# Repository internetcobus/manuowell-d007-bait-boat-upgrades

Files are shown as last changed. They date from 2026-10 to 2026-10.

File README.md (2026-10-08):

# Manuowell D007 bait boat upgrades

A stock Manuowell D007 bait boat converted to a Pixhawk 2.4.8 running ArduPilot Rover, now being upgraded to brushless thrusters on 6S.

**Start with [HANDOVER.md](HANDOVER.md)**: the current state, what's next and what's still open.

## Contents

| Path | What it holds |
|---|---|
| [HANDOVER.md](HANDOVER.md) | Current state, next steps, open questions. Keep it current. |
| [docs/01-stock-vs-converted.md](docs/01-stock-vs-converted.md) | The stock boat's specs, and what the conversion changed |
| [docs/02-brushless-upgrade.md](docs/02-brushless-upgrade.md) | Thrusters, ESCs, power module, battery options and sourcing |
| [docs/03-ardupilot-setup.md](docs/03-ardupilot-setup.md) | Rover parameters for skid steering, the power module and the battery failsafe |
| [docs/04-battery-led-indicator.md](docs/04-battery-led-indicator.md) | Reusing the stock 4 LEDs as a 4S/6S battery gauge |
| [docs/sources/](docs/sources/) | Source material kept as-is, e.g. the earlier chat export |
| [designs/](designs/) | Printed parts: thruster mounts, battery lid |

## The boat in one paragraph

Used about 4 times a year to drop bait about 180 m out. The stock electronics are gone; a Pixhawk 2.4.8 with GPS runs ArduPilot Rover with twin-motor (skid) steering, controlled from a Futaba T14SG, with a 433 MHz SiK telemetry radio to a phone (QGroundControl or Mission Planner). The bait hoppers are on servos and the lights on a relay, both driven by the Pixhawk. The goal of the current upgrade is about 1 m/s loaded outbound (now about 0.7 m/s) so the fishing lines sag less.

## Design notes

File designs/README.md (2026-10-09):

# Designs

Printed parts for the upgrade, printed on the K1C (220 × 220 × 250 mm bed). Keep each part's source (OpenSCAD `.scad` or SketchUp `.skp`) and its exported STL together in a folder per part. Export STLs from SketchUp in **millimetres**: it often defaults to inches, which makes the part 25.4 times off.

Parts (the SketchUp parts are all printed and in use; **eSUN PLA+** unless noted):

- **[Thruster mounts](thruster-mount/):** **v2** designed 2026-10-09, not yet printed: a base screwed to the hull's 4 existing posts, plus a carrier that holds the thruster and slides in from the stern. (v1, the lamp-tube pylon, is shelved.)
- **[Cable holders](cable-holders/):** glued inside the hull to keep signal and power cables apart, plus the receiver antenna tube (90 degrees). SketchUp; STL only.
- **[Servo parts](servo-parts/):** hopper servo horn for the replacement metal-geared servos. SketchUp; STL only.
- **[Pixhawk bed](pixhawk-bed/):** locates the flight controller and receiver, held with a Velcro strap. SketchUp; STL only.
- **[GPS antenna spacer](gps-antenna-spacer/):** curved spacers so the GPS bracket grips the curved bow. **Solid TPU-95.** SketchUp; STL only.
- **Battery lid:** about 10 mm taller than stock, for the 6S pack's wiring. Bay is about 98 × 73 × 82 mm.
- **PM06 mount:** 35 × 35 mm board, 30.5 × 30.5 mm hole pattern.

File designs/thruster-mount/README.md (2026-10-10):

# Thruster mount

## ⭐ Version 2 (current): base + sliding carrier, on the hull's own screw posts

Designed 2026-10-09 from Cobus's measurements ([measure/](measure/)). **Not yet printed.**

| From the stern | From below |
|---|---|
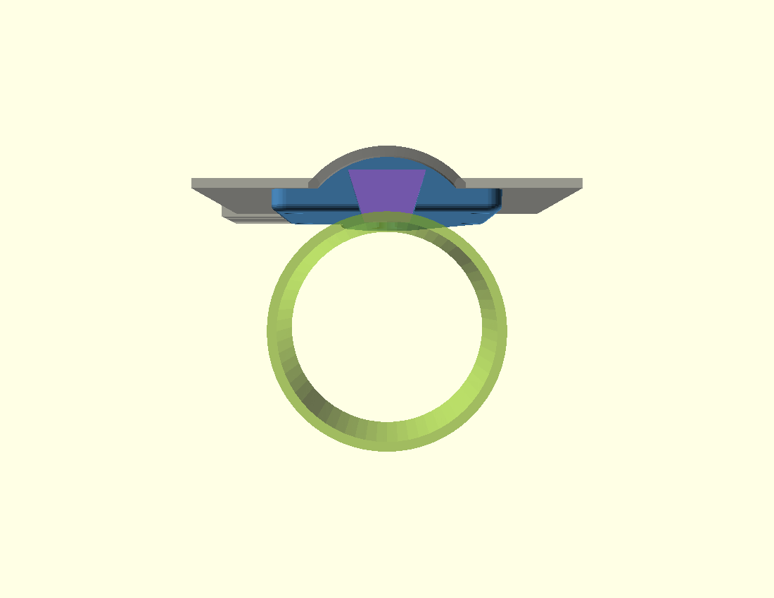
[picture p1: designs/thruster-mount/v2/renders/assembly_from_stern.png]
v2 from the stern
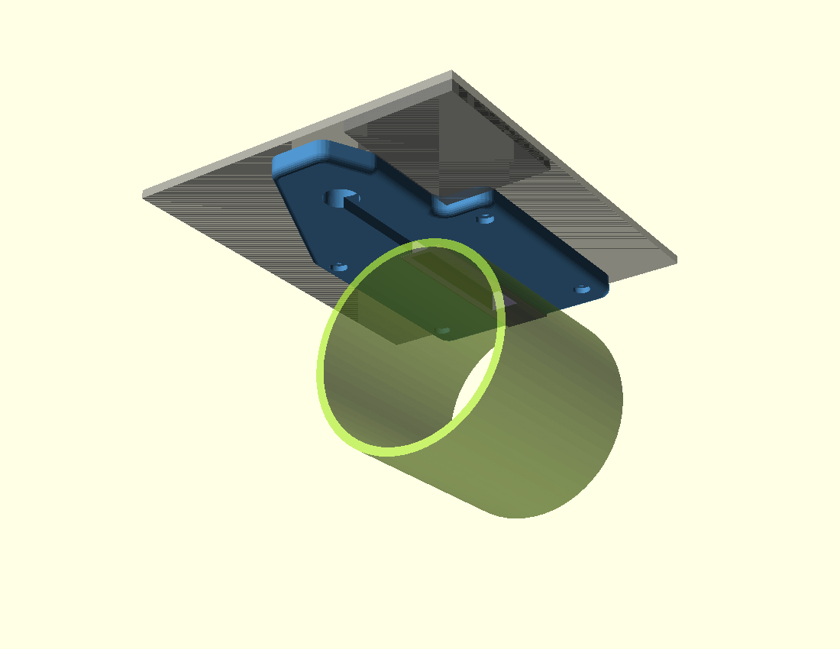
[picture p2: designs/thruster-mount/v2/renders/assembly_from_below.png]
v2 from below
|  |  |
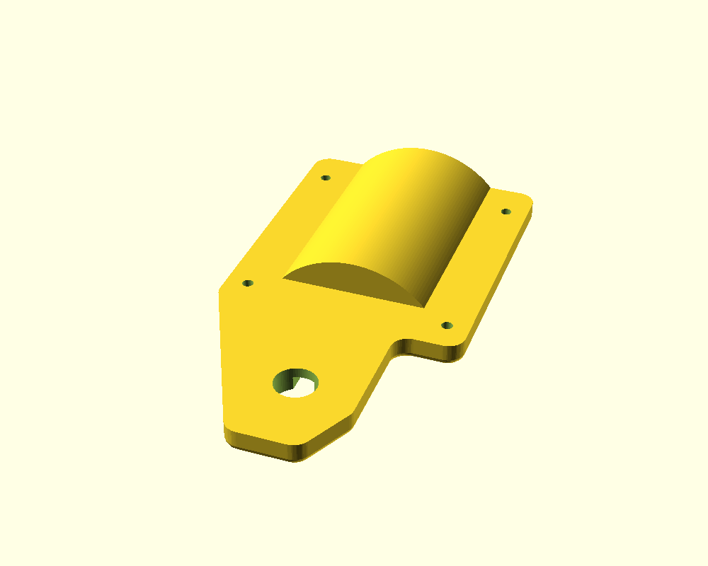
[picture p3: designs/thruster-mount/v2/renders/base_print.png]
Base, print side up
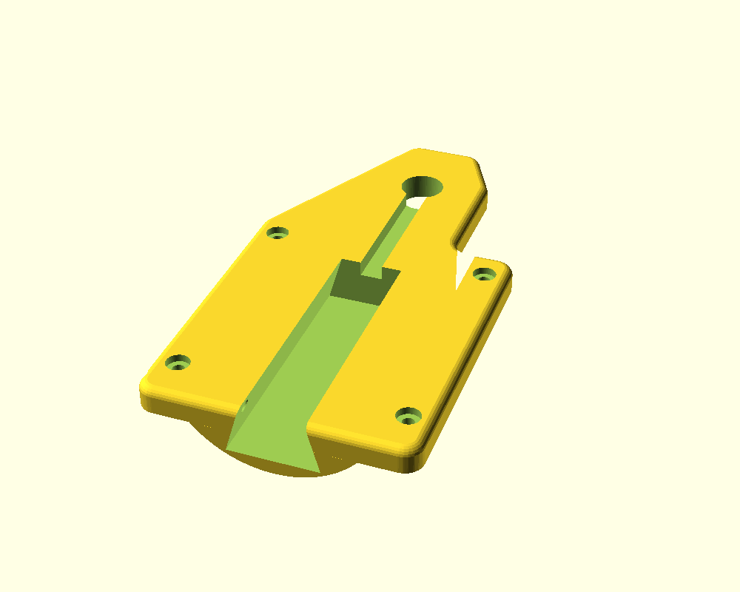
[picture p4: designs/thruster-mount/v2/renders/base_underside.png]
Base underside
|  |  |
| **Base**, as it prints: the hump fills the tunnel; corners and bottom edge rounded | **Base underside**: dovetail slot open at the stern, 4 post-screw pockets, wire channel to the wire hole |
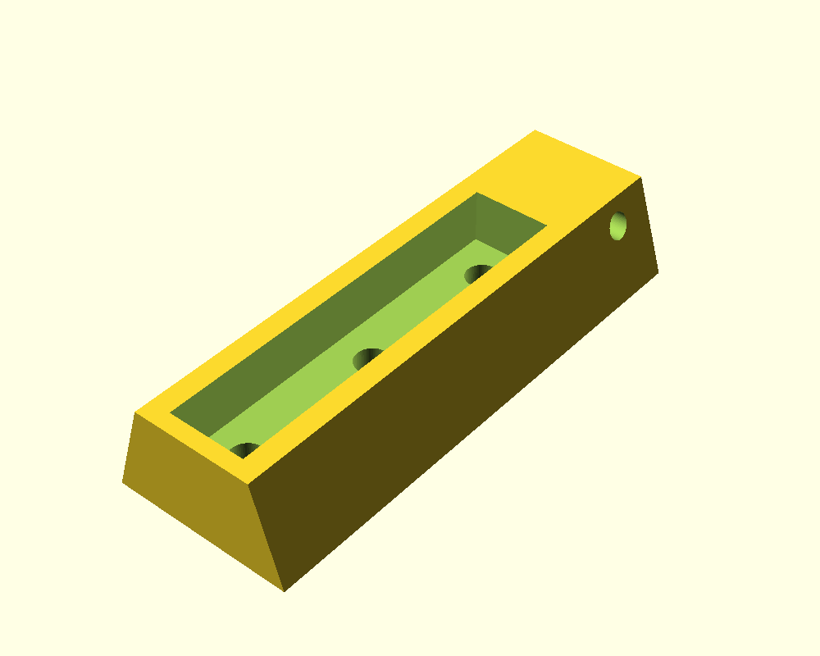
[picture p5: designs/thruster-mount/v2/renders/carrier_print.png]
Carrier
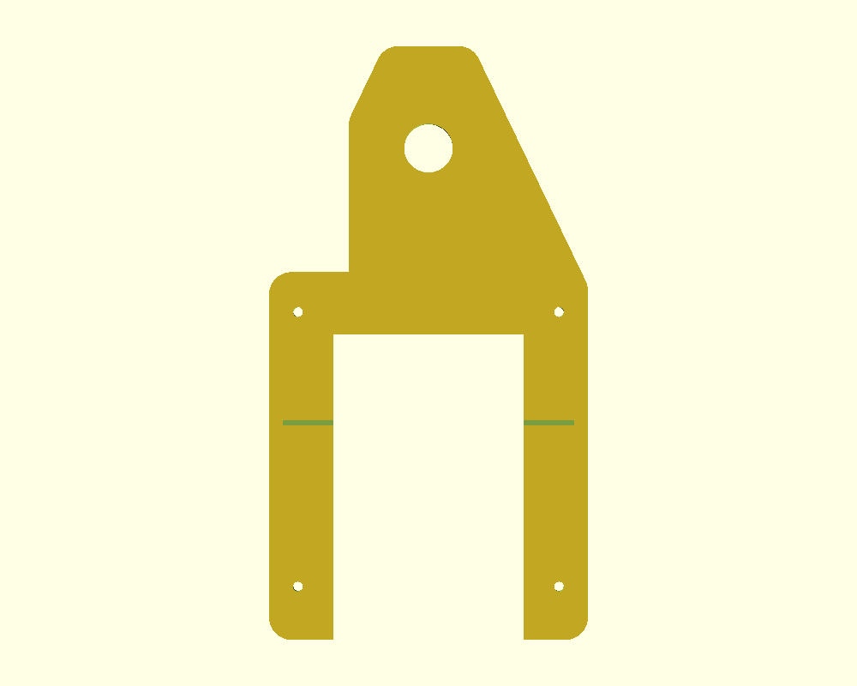
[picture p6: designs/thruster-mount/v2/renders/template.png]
Template
|  |  |
| **Carrier**, as it prints: the foot pocket, 3 M4 holes, lock-screw hole | **Template**: a 1.2 mm plate to check the 4 holes against the hull |

Each motor position has a moulded tunnel in the hull bottom (43 wide, 10 deep, 69 long) and **4 solid posts** inside that the stock motor shield screwed into from outside. The posts are closed, so the hull is already sealed there.

- **Base (blue):** fills the tunnel and screws to the 4 posts from outside, **7 mm** below the hull. Its outline corners (5 mm) and bottom edge (2.5 mm) are rounded; the top edge stays square to bed flat on the hull. The rounded stern end also gives the dovetail slot a lead-in. That gap gives water to the duct's intake. It carries on forward as a cover over the motor wires, past the wire hole to **23 mm** beyond its centre, so it also covers the hull's old mounting hole (Cobus, 2026-10-10).
- **Carrier (purple):** a dovetail bar. The thruster's foot sinks 7 mm into it and is held by 3 M4 screws from above. It slides into the base from the stern, and forward thrust pushes it against the stop at the front.
- **Lock screw:** one M3 from the **outboard** side, so reverse thrust (the boat turns by reversing one motor) can't pull the carrier out. That's why there's a left and a right version.
- **Step relief:** the strips are shallow pockets. On the **inboard** side, at 84 mm from the transom, the hull stands 4 mm proud (the template's corner caught on it, 2026-10-10). The base is **cut away** over that area (Cobus, 2026-10-10): first designed as a 4.5 mm relief, but a cover there only trapped water and added drag, and it carries no load (the nearest post screws are 10 mm aft). The cut-out's edges get the same 2.5 mm round as the rest. Where the base meets the raised area there is still a 3 mm lip, because the base's underside is 7 mm below the strip and the raised hull only 4. The outboard strip runs to the hull edge and has no step.
- **Which is which:** on each version the lock screw and the step cut-out are on opposite sides. Fit it with the **lock screw towards the hull's outer edge**; the cut-out then clears the step.

**Why two parts:** the duct's oval openings are closed, so the foot screws can only go in from above. The duct also covers the post screws. One single part could never be assembled.

**Considered and rejected, 2026-10-10: a one-piece mount.** It would be simpler to print, with no dovetail and no lock screw. But the motor would have to be bolted on first, and then the duct sits right over the 4 hull screws: the aft pair are 12 mm inside the duct's footprint, with only 15-22 mm of room below them. So they couldn't be driven from outside. It would only work with the screws driven from **inside** the hull, down through the 4 posts drilled right through. Cobus chose to keep v2: the hull stays sealed, and a motor slides out from the stern without opening the hull.

### Fitting it

0. **Remove the moulding ridge first.** A raised line about 1 mm high runs round the whole mount area: along the strips and round the wire-hole recess ([Cobus's blue line](photos/20261010_ridge_marked_cobus.jpg), 2026-10-10). The base sits on it, which is what lifted the dovetail test piece. Shave it flush with a chisel held bevel-up and flat, or a scraper, then a sanding block (~240). Never go below the surface; the hull is about 3 mm. Check with a straight edge. The sanding also gives the epoxy a key.
1. **Pilot holes:** open the hull's 2 mm holes to **2.4 mm**, about **12 mm deep** from outside. Tape round the drill bit marks the depth. Hull and post together are 17.5 mm, so this leaves the post's closed top intact. Do one post first and check it doesn't crack.
2. **Base:** screw it to the 4 posts with **ST2.9 × 13**, with the thruster off. A dab of marine sealant on each screw stops water wicking into the posts. Epoxy bedding is **optional** (decided 2026-10-10): at about 6 N per screw at full thrust, the screws carry the load. Bedding would only help spread knocks.
3. **Foot holes:** drill the thruster foot's 3 mm holes out to **3.3 mm** and tap them **M4**, to their existing depth only. **Never drill through.** The foot sits on the duct, and a bolt end would hit the propeller.
4. **Carrier:** bolt the foot into it on the bench, with 3 × **M4 countersunk**. Drop the M3 nut into its slot in the carrier's top.
5. **Assemble:** slide the carrier in from the stern until it stops, then fit the **M3 × 40** lock screw from the outboard side.
6. **Wires:** run them along the channel and up through the wire hole. Seal the hole with a cable gland or potting.

### Parts for both sides

| Qty | Part | For |
|---|---|---|
| 8 (+ spares) | **ST2.9 × 13** stainless pan-head self-tapper | Base to the 4 posts, each side |
| 6 | **M4 countersunk** stainless, about **× 12**. Length to check: 6.1 mm goes through the carrier, the rest into the foot | Foot to carrier |
| 2 | **M3 × 40** stainless machine screw + **2 M3 nuts** | Lock screws |
| 1 each | 2.4 mm and 3.3 mm drill, **M4 tap** | Pilot holes and foot holes |
| 1 | Marine sealant (e.g. Sikaflex); thickened epoxy only if you choose to bed the bases | Screws, and optional bedding |
| 2 | Cable gland, or sealant to pot the wire holes | Wire holes |
| — | ABS (or ASA) filament | Bases and carriers |

The v1 shopping list (lamp tube, nuts, rubber washers) is no longer needed.

### Print and check first

| File | Check |
|---|---|
| `v2/v2_template_right.stl`, `v2/v2_template_left.stl` | Lay it on the hull. Do the 4 holes land on the 2 mm pilot holes, does the window match the tunnel, and does it now sit flat past the step? ✅ 2026-10-10: the first template (no notch) matched all 4 holes; only the corner on the step lifted it. It's a flat plate, so one turned over is the other. |
| `v2/v2_fit_dovetail_ladder_right.stl` | **Clearance ladder, print in ABS.** Three 14 mm base slices, marked with 1 / 2 / 3 notches = **0.10 / 0.15 / 0.20 mm** a side, plus a 14 mm carrier. Pick the slice the carrier slides into with a light push and no wobble; I then set `dv_clear` to it. **Result (2026-10-10, ABS): 0.10 fits best, no wobble; `dv_clear` is now 0.10 and the base and carrier STLs are re-exported.** |

**First dovetail test (2026-10-10, PLA):** the M3 nut dropped in perfectly, but the carrier had play all round. The cause was the design, not the PLA. The walls were only about 9° off vertical (18 / 22 mm), so 0.3 mm of side gap let the carrier sink about **2 mm**: drop = gap ÷ wall slope. Now 16 / 24 mm (twice the slope) at 0.15 mm a side: the carrier sinks about 0.5 mm. ABS wouldn't have fixed it, because both parts shrink alike.
| `v2/v2_base_right.stl`, `v2/v2_carrier_right.stl` | Right-hand thruster: lock screw from the right (outboard) side |
| `v2/v2_base_left.stl`, `v2/v2_carrier_left.stl` | Left-hand thruster |

Print in ABS or ASA (not PLA: sun and water), 4+ walls, 40 %+ infill. Both parts are already laid flat for printing: the base on its underside, the carrier on its top.

### Not yet measured (marked `VERIFY` in the .scad)

- **The rail across the tunnel:** no groove for it (Cobus, 2026-10-09). It's only 0.5 mm high, and the base sits 0.3 mm off the tunnel roof for the epoxy, so the bedding takes it up. If the base rocks on a dry fit, sand the rail down. The groove can be switched back on with `rail_groove = true`; its position (49 mm from the transom) was read off photo 1 by scale, and the template's scribed line checks it.
- **The wire hole:** about 11 mm across.
- **How deep the foot's 3 holes go.** That decides the M4 screw length.
- **Where the raised area starts across:** taken from 18 mm off the centreline (`step_x0`; the tunnel's frame line is at 21.5). **Also check the other tunnel** has the same step on its inboard side; the model assumes the hull is mirror-symmetric.

### Files

`thruster_mount_v2.scad` is the source. Set `part` to `base`, `carrier`, `template`, `fit_dovetail` or `all`, and `side` to `right` or `left`. Its `assert`s stop a change that would make the carrier hit the hull or leave too little plastic. For both sides, OpenSCAD intersections show the base, carrier, hull (including the step) and thruster don't overlap; the only contact is the wings on the hull, the bedding face. Negative tests prove the checks work: with the step cut-out moved away, the base and hull overlapped by 441 mm³; with the slot too tight, base and carrier overlap by 408 mm³. Both base STLs are one closed solid. `part = "none"` draws nothing, for check scripts that `include` the file. Re-export after any change, e.g.
`openscad -D 'part="base"' -D 'side="left"' -o v2/v2_base_left.stl thruster_mount_v2.scad`

---

## Version 1 (shelved 2026-10-09)

Shelved because the hull turned out to have its own tunnel and screw posts, and the lamp tube only came in 15 mm locally. Kept for the record.

A printed pylon that hangs each 62 mm brushless thruster from the **stock motor-post hole**, on a **steel hollow M10 × 1 lamp tube** that also carries the wires. The hull gets no new holes. The part is symmetric, so print two.

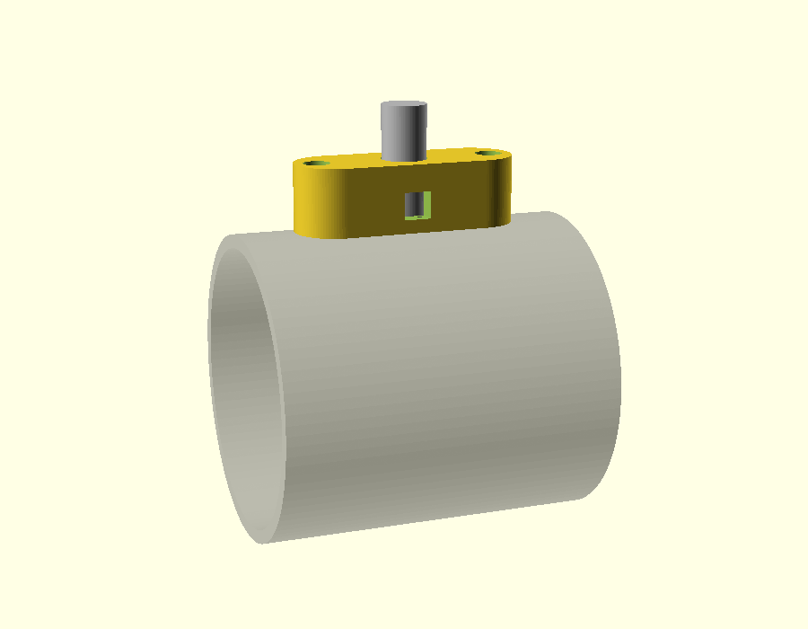
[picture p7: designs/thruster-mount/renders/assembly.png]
Pylon on a dummy thruster


| Render | |
|---|---|
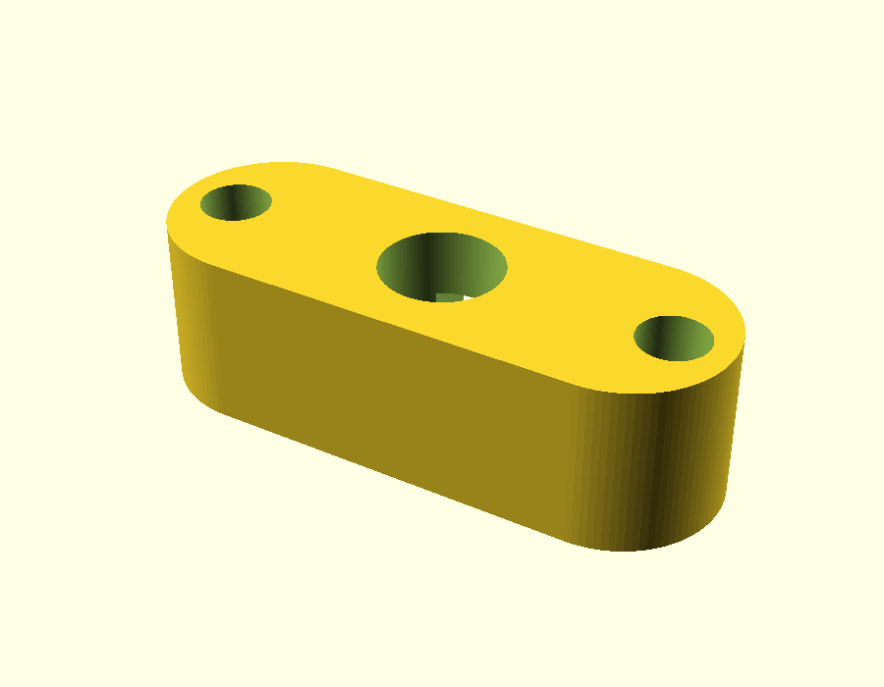
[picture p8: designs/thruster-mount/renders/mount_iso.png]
Hull face
|  | Hull face: tube bore in the middle, screw-head pockets at each end |
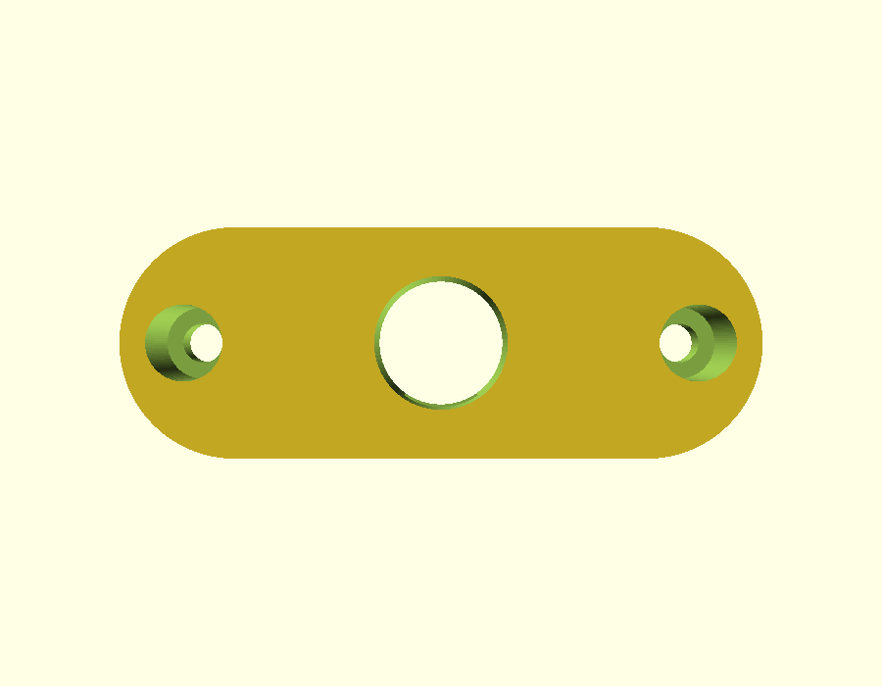
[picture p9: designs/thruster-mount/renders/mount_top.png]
Underside
|  | Looking down through it: the screw clearance holes under the head pockets |

## Status (2026-10-08)

**Version 1, not yet printed.** It is designed from the stock pod's dimensions and the thruster specs; nothing has been measured on the boat yet. Print the two fit tests first.

## How it goes together

```
 inside hull     inner nut + steel washer + rubber washer
 ════════════════╪═══════════════  hull, existing 11 mm hole
                 │  ring of marine sealant on the pylon's top face
             ┌───┴───┐
             │ pylon │  the tube threads into a nut captured in the pylon's base
             └─┬───┬─┘  the wires leave through the side slot
          ╭────┴───┴────╮
          │  thruster   │  2 screws, 40 mm apart, heads inside the pylon
          ╰─────────────╯
```

1. Press an M10 × 1 lamp nut into the hex pocket in the pylon's base.
2. Bolt the pylon to the thruster: two screws down through the head pockets into the thruster's **outer** two holes. The middle hole sits under the tube and stays empty.
3. Thread the tube into the captured nut, flush with the nut's underside. Feed the thruster's three wires in through the side slot and up the tube.
4. Run a ring of marine sealant (e.g. Sikaflex) round the tube on the pylon's top face. Keep it **inside** the head pockets: less than 7 mm from the tube's centre.
5. Push the tube up through the stock hole. Inside the hull, fit a rubber washer, a steel washer and the inner nut, then tighten it so the pylon clamps the hull. **Line the thruster up with the boat's centreline before the sealant sets.** The sealant is also what stops the pylon twisting.
6. Seal the wires where they leave the top of the tube, e.g. with silicone or adhesive-lined heat-shrink.

## Parts per side

| Part | Note |
|---|---|
| Printed pylon | ASA, 4+ walls, 40 %+ infill, thruster face down on the bed (as modelled) |
| M10 × 1 hollow steel lamp tube | Cut to **27 mm** (the `.scad` prints the length for the current settings) |
| 2× M10 × 1 lamp nuts | One captured in the pylon, one inside the hull |
| M10 steel washer + rubber washer | Inside the hull |
| 2× M3 socket-head screws, stainless | **Length to be decided** once the thruster's holes are checked. The pylon gives 4 mm of grip. |
| Marine sealant | Sikaflex or similar |

## Check these before printing the full pylon

Every value marked `VERIFY` in `thruster_mount.scad` is an assumption:

- **The thruster's holes:** three 3 mm holes in a line along the top, 20 mm apart (Cobus, 2026-10-08). The pylon uses the outer pair, 40 mm apart. Still to check: are they threaded? A tapped M3 hole measures about 2.5 mm, so 3 mm may mean plain holes for self-tappers.
- **50 mm of flat hull at each post hole.** The pylon is 50 mm long to reach the outer holes; the stock pod's saddle was only 35 mm.
- **The lamp nut:** 13 mm across the flats and 3 mm thick is assumed. Measure the ones you buy and set `nut_af` and `nut_h`.
- **The hull wall at the post hole:** 3 mm assumed. It only changes the tube length.
- **The duct's outside diameter:** 68 mm assumed (62 mm opening plus about 3 mm walls). With the 15 mm `drop`, the thruster's axis sits about 49 mm below the hull. Check that against how shallow the water is where you launch.
- **Is the hull flat where the pylon sits?** If not, the top face needs to follow the curve.

## Fit tests (a few grams each)

| File | What to check |
|---|---|
| `thruster_mount_fit_bottom.stl` | The two screw holes line up with the thruster's outer holes; the lamp nut presses in and doesn't spin; the tube threads in |
| `thruster_mount_fit_top.stl` | The hull face sits flat against the hull at the post hole |

## Files

- `thruster_mount.scad`: the source. Set `part` to `mount`, `fit_bottom`, `fit_top`, or `all` (an assembly preview, not for printing). Its `assert`s stop a parameter change that would break a wall.
- `thruster_mount_*.stl`: exported from the current settings. Re-export after any change:
  `openscad -D 'part="mount"' -o thruster_mount_mount.stl thruster_mount.scad`
- `renders/`: preview images. OpenSCAD is a snap here and can't write to `/tmp`, so render into the repo.

## Design notes

- **Why a steel tube:** about 1.7 kg of thrust per side bends the post where it meets the hull. A printed 11 mm post would see roughly 7 MPa there, close to where printed layers separate, and the load repeats on every run.
- **Why the outer pair of holes:** the thruster's middle hole is directly under the tube. Using the outer two, 40 mm apart, keeps the tube centred and resists the thrust better than a 20 mm pair.
- **Why sealant, not an O-ring:** the sealant also stops the pylon twisting, and it copes with a hull that isn't perfectly flat. Sealant on the face plus the rubber washer inside the hull do the sealing.
- **Footprint:** 50 × 18 mm, long enough for the outer screw pair, with rounded ends to keep it streamlined.
- **If a pylon still twists:** set `pin_d` (e.g. 3.2) to add a locating pin. That needs one small new hole in the hull.

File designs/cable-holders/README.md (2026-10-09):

# Cable holders

Drawn by Cobus in SketchUp during the upgrade. Added 2026-10-08 from `Cable holders.stl`.

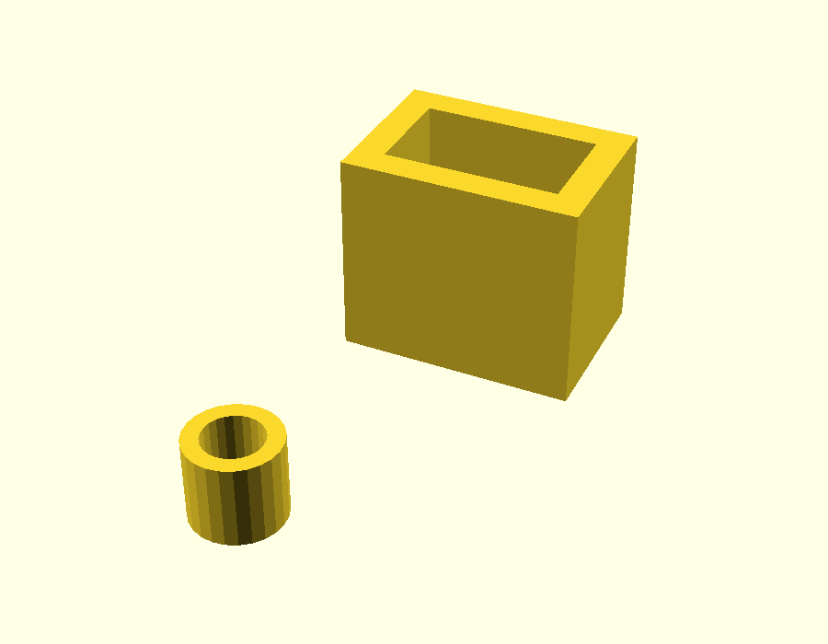
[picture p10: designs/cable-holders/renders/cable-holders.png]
Cable holders
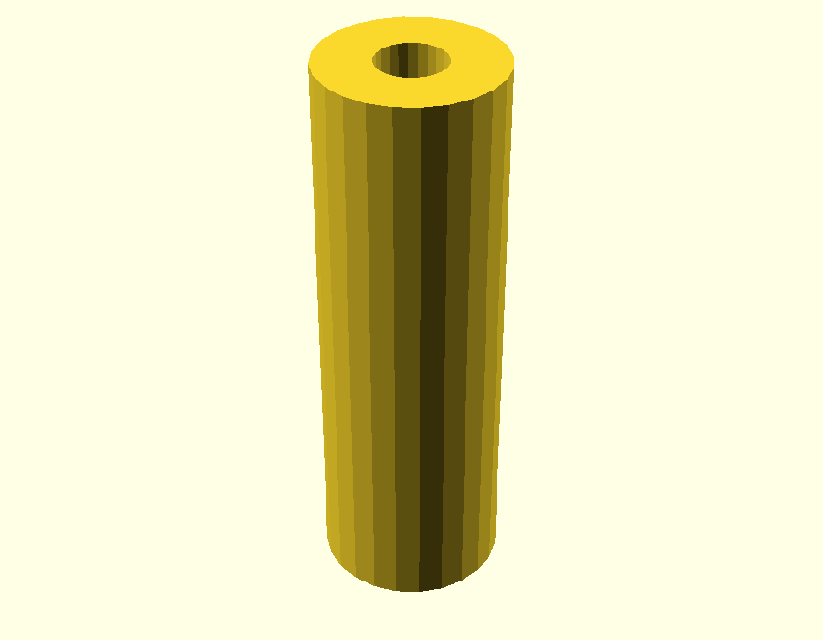
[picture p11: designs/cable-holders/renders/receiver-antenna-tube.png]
Receiver antenna tube
|  |  |
|---|---|
| `cable-holders.stl` | `receiver-antenna-tube.stl` |

## What it's for

Glued to the inside of the hull to keep the **signal cables and the power cables apart**. The cables run through the inside of these parts.

The **receiver antenna tube** holds the receiver's antenna wire at **90 degrees** for the best signal. It was drawn on the [GPS antenna spacer](../gps-antenna-spacer/) plate and moved here on 2026-10-09 as its own file.

Described by Cobus, 2026-10-09. **Printed in eSUN PLA+ and in use.**

## What's in the file

In millimetres:

| File | Part | Size (mm) |
|---|---|---|
| `cable-holders.stl` | Round spacer, with a hole through it | 8.9 × 8.9 × 8.0 |
| `cable-holders.stl` | Open-topped rectangular box | 23.0 × 16.0 × 20.0 |
| `receiver-antenna-tube.stl` | Tube, 2.5 mm bore (measured from the mesh) | 6.5 × 6.5 × 20.0 |

Both meshes are watertight (no open edges). The tube's triangles were copied unchanged from the GPS spacer plate.

## Source

The SketchUp `.skp` file isn't in the repo yet. Add it here as `cable-holders.skp` so the original can be reopened and changed.

## Changing it

Without the `.skp`, changes are made on this STL in OpenSCAD: adding or cutting features, or scaling. Redrawing it as a parametric `.scad` is the better route if it will keep changing.

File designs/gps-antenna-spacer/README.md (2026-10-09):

# GPS antenna spacer

Drawn by Cobus in SketchUp during the upgrade. Added 2026-10-08 from `GPS antenna spacer.stl`.

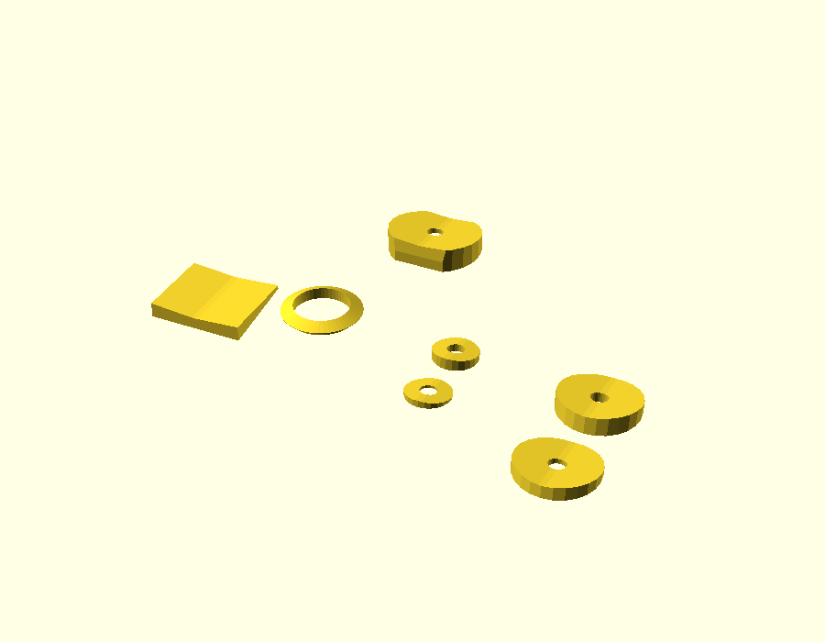
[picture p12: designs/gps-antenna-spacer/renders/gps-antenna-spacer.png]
GPS antenna spacer


## What it's for

The GPS antenna is mounted on the **front of the hull, on the centreline**. The hull isn't flat there, so these curved spacers sit between the antenna bracket and the hull: the bracket can be tightened firmly and still grip the curve.

Described by Cobus, 2026-10-09. **Printed in solid TPU-95** (100 % infill), so the spacers flex to follow the hull's curve exactly. **In use.**

The original plate also held the receiver antenna tube. That isn't a GPS part, so on 2026-10-09 it moved to the [cable holders](../cable-holders/) as `receiver-antenna-tube.stl`.

## What's in the file

`gps-antenna-spacer.stl` is a print plate with 7 parts, in millimetres:

| Part | Size (mm) |
|---|---|
| Curved square pad | 17.0 × 14.0 × 2.7 |
| Ring | 14.4 × 14.4 × 2.1 |
| Shaped washers with a hole (4) | about 14-17 × 14 × 2.2-4.4 |
| Small washers (2) | 8.0 × 8.0 × 1.2 and 2.2 |

Watertight mesh (no open edges). The plate is now 7.3 mm tall (it was 22 mm with the tube).

**Print in TPU-95, solid.** In PLA+ these spacers wouldn't follow the curve, and the bracket would rock.

## Source

The SketchUp `.skp` file isn't in the repo yet. Add it here as `gps-antenna-spacer.skp` so the original can be reopened and changed.

## Changing it

Without the `.skp`, changes are made on this STL in OpenSCAD: adding or cutting features, or scaling. Redrawing it as a parametric `.scad` is the better route if it will keep changing.

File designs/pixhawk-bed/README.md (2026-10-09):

# Pixhawk bed

Drawn by Cobus in SketchUp during the upgrade. Added 2026-10-08 from `Pixhawk 4 bed.stl`.

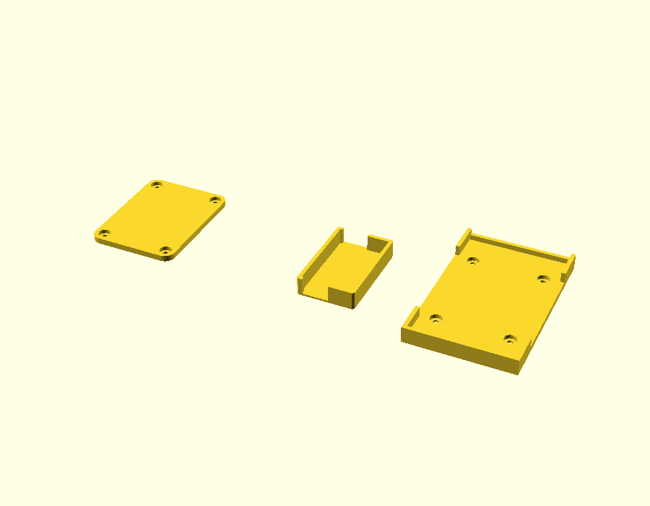
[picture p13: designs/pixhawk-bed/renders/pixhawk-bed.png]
Pixhawk bed


## What it's for

Holds the **flight controller and the RC receiver** in the right position, secured with a **Velcro strap**.

Described by Cobus, 2026-10-09. **Printed in eSUN PLA+ and in use.**

## What's in the file

`pixhawk-bed.stl` is a print plate with 3 parts, in millimetres:

| Part | Size (mm) |
|---|---|
| Flat plate, 4 corner holes | 44.5 × 59.0 × 3.0 |
| Small open tray | 29.0 × 46.8 × 9.0 |
| Large tray with side rails and 4 holes | 53.6 × 85.5 × 8.0 |

🚨 The mesh has **12 open or doubled edges**; most slicers repair this on import.

🚨 As laid out, the plate is **220.05 mm** wide, just over the K1C's 220 mm bed. Move the parts closer together in the slicer.

The file is called "Pixhawk 4 bed" but the boat runs a Pixhawk 2.4.8. The large tray (53.6 × 85.5 mm) would fit a 2.4.8, which is about 50 × 81.5 mm.

## Source

The SketchUp `.skp` file isn't in the repo yet. Add it here as `pixhawk-bed.skp` so the original can be reopened and changed.

## Changing it

Without the `.skp`, changes are made on this STL in OpenSCAD: adding or cutting features, or scaling. Redrawing it as a parametric `.scad` is the better route if it will keep changing.

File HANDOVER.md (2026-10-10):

# Handover: current state

_Last updated: 2026-10-10_

## Where things stand

- **Running today (working well):** Pixhawk 2.4.8 + GPS on ArduPilot Rover, stock 390 brushed thrusters on two CL9030 brushed ESCs, stock 7.4 V 10 Ah Li-ion pack. The Pixhawk is powered from an ESC's 5 V output, so it cannot read the battery yet.
- **Brushless upgrade:** 480 Kv ducted thrusters (CW/CCW pair) and two BLHeli 40 A bidirectional ESCs ordered. Duct opening measured at 62 mm, which confirms the thrusters match the specs in [the chat export](docs/sources/2026-10-08-earlier-chat-export.md), not the 1000 KV listing.
- **Decided:** go **6S**. Cap `MOT_THR_MAX` at about 90%, because a full 6S pack (25.2 V) is slightly over the 24 V rating.
- **Power module:** Holybro **PM06** on hand, **not fitted yet**.

## Next steps

1. Wait for the thrusters; bench test them with the props in water.
2. Decide the pack: 2× Auline 21700 S70 6S 4500 mAh in parallel (AliExpress), or a no-BMS Molicel P42A 6S2P (Akita or DIY). See [docs/02](docs/02-brushless-upgrade.md).
3. Weigh the stock battery; do the bath/ballast hull test.
4. **Thruster mounts: v2** ([designs/thruster-mount](designs/thruster-mount/)). A base screwed to the hull's 4 existing posts (ST2.9 × 13) and a dovetail carrier that holds the thruster (3 × M4 into the tapped foot), slides in from the stern and is locked by one M3 × 40 from the outboard side. Left and right versions.
   - **Tested 2026-10-10:** the template's 4 holes line up. The base is now cut away over a 4 mm step on the inboard side (84 mm from the transom). A ~1 mm gap on the curve came from a moulding ridge round the mount area, which Cobus shaved flush. The first dovetail (PLA) was loose because its walls were too steep; it's now 16/24 mm, and the ABS clearance ladder picked **0.10 mm** (no wobble). The wire cover now runs 23 mm past the wire hole to cover the old mounting hole.
   - **Decided:** stay with two parts (one-piece rejected, see the mount README); epoxy bedding optional.
   - **Confirmed 2026-10-10:** ridge shaved and the base now sits well; the reprinted template (with the 23 mm tip) fits; the other tunnel has the same inboard step, so the left part's mirrored cut-out is right.
   - **Next:** a PLA+ mock-up of the right base and carrier with the thruster fitted, to check the whole assembly. Then measure the foot holes' depth (M4 length) and the wire hole, buy the screws, print the real parts.
   - Still to design: the taller battery lid.
5. **SketchUp parts added 2026-10-08** (STL only): [cable holders](designs/cable-holders/), [servo parts](designs/servo-parts/), [Pixhawk bed](designs/pixhawk-bed/), [GPS antenna spacer](designs/gps-antenna-spacer/). All printed and in use: eSUN PLA+, except the GPS spacers in solid TPU-95. Purposes recorded 2026-10-09; the receiver antenna tube moved to `cable-holders/`. Still to do: add the `.skp` files beside the STLs.
6. Fit the PM06; configure the Rover parameters and battery failsafe ([docs/03](docs/03-ardupilot-setup.md)); build the LED indicator ([docs/04](docs/04-battery-led-indicator.md)).

## Open questions

- **PM06 connector:** the PM06 ends in a 6-pin JST-GH plug; the Pixhawk 2.4.8 power port is a 6-pin DF13. An adapter cable is needed. Check which PM06 version it is (V1 is 2S-6S, V2 is 2S-14S); either covers 6S.
- **5 V supply:** with the PM06 powering the Pixhawk, decide what each ESC's 5 V / 3 A BEC feeds (servos? LED MCU?). Never connect two BECs to the same rail.
- Which Pixhawk outputs drive the relay and the hopper servos (motors: `SERVO1` / `SERVO3`).
- Which RC receiver is paired with the T14SG, and how it connects (SBUS?).
- Which failsafes are configured today.
- Rover is set up as a Rover with twin motors, not the Boat frame (`FRAME_CLASS = 2`). It may be worth trying Boat.

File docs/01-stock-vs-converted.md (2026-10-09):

# Stock vs converted

Conversion done before 2026-10-08: the stock electronics were removed and replaced with a Pixhawk.

| Item | Stock D007 | Converted |
|---|---|---|
| Control electronics | Stock board | Removed; **Pixhawk 2.4.8** and the RC receiver on a printed [bed](../designs/pixhawk-bed/) with a Velcro strap |
| Firmware | Stock | **ArduPilot Rover**, twin drive motors (skid steering) |
| Navigation | Built-in GPS + compass, limited: 3 stored fishing spots, auto-pilot to a spot, auto-return | **GPS** on the Pixhawk; full missions and waypoints. Antenna on the bow, on the centreline, on printed [curved spacers](../designs/gps-antenna-spacer/) |
| Failsafes | Low-power alarm, low-power auto-return, lost-signal auto-return | Rover failsafes (what is configured is not yet recorded) |
| RC | Stock remote, about 500 m range; the shop page also lists "4G mobile" | **Futaba T14SG** |
| Telemetry | None | **SiK 433 MHz** on **TELEM1**, to a phone (QGroundControl or Mission Planner) |
| Motor drive | Stock board | Two **CL9030** brushed ESCs, one per motor |
| Motors | Two 390 brushed thrusters (see below) | Unchanged |
| Lights | Two LEDs, front and rear | Switched by a **relay** from the Pixhawk |
| Battery | 7.4 V 10 Ah Li-ion | Unchanged |
| Battery indicator | 4 LEDs (3 blue + 1 red), 2S only | Planned rebuild, see [04](04-battery-led-indicator.md) |
| Pixhawk power | n/a | From an ESC's 5 V output; no battery reading |
| Wiring | Stock | Signal and power cables kept apart by printed [cable holders](../designs/cable-holders/); the receiver antenna held at 90 degrees |
| Bait hoppers | Two side-release hoppers, 2 kg total, on **continuous-rotation** servos | **Normal (positional) metal-geared servos** on Pixhawk outputs, with a printed horn ([servo parts](../designs/servo-parts/)) |
| Fish finder | Not supported | — |

## Stock specs

Source: [Carpe Diem Online, D007 Classic Series](https://carpediemonline.co.za/online-store/d007-classic-series/). The page's heading reads **D008**, although the URL says D007, so a figure may belong to the D008.

- **Hull:** 53 × 33 × 22 cm overall, hull 50 × 30 × 18 cm, virgin ABS, carbon-fibre finish, 3 kg, stainless steel folding handle.
- **Battery:** D008/V017 pack, 7.4 V, 10 Ah, Li-ion, 10 × 5 × 4 cm, listed at 0.5 kg (the export estimates about 400 g; to be weighed). R1,127 as a spare from [Carpe Diem Online](https://carpediemonline.co.za/online-store/d008-v017-battery-10ah/).
- **Battery bay:** about 98 × 73 × 82 mm. A taller lid can be printed.
- **Motors:** a pair of SkyArea 390-size brushed underwater thrusters ([AliExpress](https://www.aliexpress.com/item/1005006050172879.html), R340 a pair): 30 W, rated 5-12 V, about 10,000 rpm, 26 mm 3-blade prop, ABS shell, silicone seal. About 130 mm long overall (87 mm body), mounted on an 11 mm threaded post (37 mm tall, 28 mm threaded). No current rating listed; about 4 A each running, by estimate from 30 W at 7.4 V.
- **Performance today:** about 0.7 m/s loaded.

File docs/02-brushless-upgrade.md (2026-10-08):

# Brushless upgrade

## Goal

About **1 m/s loaded outbound** (now about 0.7 m/s) so the fishing lines sag less, which is a thrust problem. About 2 m/s empty on the return is a bonus. Loaded speed is capped by hull speed, about 0.9-1 m/s for a hull this size, so the extra thrust shows more on the return.

## Thrusters (ordered, AliExpress)

Brushless, ducted, 4-blade, CW/CCW pair:

- **480 Kv**, 12-24 V, 13 A, 30-200 W, about **2 kg thrust each at 24 V**
- 162 g each, 75 mm long, **62 mm diameter** (duct opening measured 2026-10-08), 250 mm leads
- Mounting: **three 3 mm holes in a straight line along the top, 20 mm apart** (Cobus, 2026-10-08). Threaded or plain not yet checked. The [thruster mount](../designs/thruster-mount/) uses the outer pair.

A different listing, [KINGMODEL 4000074645091](https://www.aliexpress.com/item/4000074645091.html), was looked at on 2026-10-08. It describes 1000 KV / 20 A / 74 mm thrusters with a PLA shell and a semi-submersible prop. The 62 mm measurement shows these are not those thrusters, so ignore that listing's figures.

## ESCs (ordered)

Two BLHeli ESCs: **40 A (50 A burst), 2S-6S, 5 V / 3 A BEC, bidirectional**, programmable. They replace the CL9030s, which are brushed only.

## Power module

Holybro **PM06**, on hand, not fitted yet. Per [Holybro's PM06 V2 specs](https://www.getfpv.com/electronics/autopilot-systems/pm06-14s-power-module.html): 2S-14S, 60 A rated (120 A for under 60 s), 5.1-5.3 V / 3 A output to the Pixhawk, XT60 on 12 AWG (rated 30 A continuous, 60 A for under a minute), 35 × 35 mm, 24 g. The original PM06 (V1) is 2S-6S. Either version covers 6S.

- **Connector:** the PM06 has a 6-pin **JST-GH** cable; the Pixhawk 2.4.8 power port is a 6-pin **DF13**. An adapter cable is needed.
- The XT60 lead is rated 30 A continuous. Full throttle on 6S is about 26 A in total, so that's within its rating but close.

## Why 6S

The rated thrust is at 24 V. 4S gives only about 0.75-1 kg per thruster; 6S about 1.7 kg. A full 6S pack is 25.2 V, slightly over the 24 V rating, so cap `MOT_THR_MAX` at about 90%.

## Battery options

Energy: about 14 Wh per drop at cruise, about 33 Wh per drop at full throttle on 6S. Plan on 80% of the pack being usable.

| Pack | Weight | Top speed loaded / empty | Drops cruise / full |
|---|---|---|---|
| 4S 5500 LiPo | ~550 g | 0.9-1.1 / 1.5-1.8 m/s | ~4-5 / same |
| 6S 5000 LiPo | ~750 g | 1.2-1.4 / 2+ m/s | ~6 / ~2-3 |
| 6S1P 21700 P42A | ~420 g | 1.15-1.3 / ~2 m/s | ~5 / ~2 |
| 6S2P 21700 P42A (8,400 mAh, ~181 Wh) | ~880 g | 1.2-1.4 / 2+ m/s | ~10 / ~4 |

- Both LiPos (5000+ mAh) are probably too long for the 98 mm bay. Measure first.
- A 6S2P P42A pack is about 450-500 g heavier than the stock pack; the whole upgrade is about 750-800 g over stock.
- **6S2P fit:** a 4 × 3 upright brick is about 88-92 × 66-70 × 74-78 mm and fits the bay. Glue the cells, no printed holders; a lid about 10 mm taller for the wiring.

## Sourcing (South Africa)

- **Molicel P42A** (21700, 4200 mAh, 45 A): DIYElectronics (~R209), The Vapery, Vaporworx (~R230), Vanilla Vape.
- **Akita Custom Batteries** (Randburg, 011 704 2429, info@akita.co.za) quoted a 6S2P Samsung 30P (6,000 mAh) with a 12 A BMS for R2,662 incl. VAT.
  - The 12 A BMS is too small: full throttle is about 26 A. They have no 30 A BMS.
  - Their concern about the P42A was mistaken; it is rated 45 A per cell.
  - Fix: ask for **no BMS** (XT60 plus a 7-pin JST-XH balance lead) or a charge-only BMS.
- **AliExpress best fit:** 2× **Auline 21700 S70 6S 4500 mAh** (75 × 64 × 42 mm, 70 A each) in parallel, about 9,000 mAh, standing side by side in the bay.
  - Buy a matched pair, parallel them only at equal voltage, with an XT60 Y-harness.
  - Check whether lithium ships to South Africa.

## Hull

Probably fine for now. Risks: pod mounting strength under thrust, stern freeboard, ESC heat.

- **Bath test:** about 1 kg of ballast plus a full bait load. 3 cm or more of freeboard is OK; about 2 cm is marginal.
- **Fallback:** print a hull on the K1C (220 × 220 × 250 mm bed) in sections, in ASA, with an epoxy or fibreglass skin.

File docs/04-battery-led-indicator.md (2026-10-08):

# Battery LED indicator

The stock boat has a 4-LED battery gauge (3 blue + 1 red) that only understands 2S. The plan (options 1 + 3 from the [chat export](sources/2026-10-08-earlier-chat-export.md)): reuse those LEDs, driven by a small microcontroller, with the Pixhawk battery failsafe as the real safety net.

## Hardware

- MCU: ATtiny85, Nano or ESP32.
- Battery voltage through a divider, e.g. 100k / 10k.
- Powered from an ESC's 5 V BEC.
- Bypass the stock board: cut its battery feed, isolate the LEDs from its chip, and drive them through resistors: 150-330 Ω for blue, 220-470 Ω for red, at 5 V.

## Logic

Auto-detect 4S or 6S at power-up, then show the per-cell voltage:

| Per cell | LEDs |
|---|---|
| 3.95 V or more | 3 blue |
| 3.80 V or more | 2 blue |
| 3.65 V or more | 1 blue |
| below 3.65 V | red |
| below 3.5 V | red, flashing |

These thresholds suit LiPo. Lower them for Li-ion.

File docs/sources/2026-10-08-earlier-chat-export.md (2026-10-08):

# Manuowell D007 Bait Boat — Motor & Battery Upgrade (Session Export)
Exported: 8 Oct 2026

## Boat & current setup
- Manuowell D007 bait boat, used ~4×/year, drops ~180 m out
- Pixhawk 2.4.8 + GPS on ArduPilot Rover (working well); telemetry via SiK radio to phone
- Stock thrusters: 390 brushed, 7.4V/2S, ~10,000 RPM, 26 mm 3-blade prop, inline pods
- Stock battery: 7.4V 2S Li-ion, ~10 Ah (~400 g est. — weigh to confirm)
- Battery bay: ~98 × 73 × 82 mm (can print a taller lid)
- Stock 4-LED voltage indicator (3 blue + 1 red), 2S only

## Goal
- ~1 m/s loaded outbound so fishing lines sag less (thrust problem); ~2 m/s empty return is a bonus
- Current loaded speed: ~0.7 m/s

## Thrusters & ESCs (ordered, AliExpress)
- Brushless ducted 4-blade thrusters, CW/CCW pair
  - 480 Kv, 12–24 V, 13 A, 30–200 W, ~2 kg thrust each @ 24 V
  - 162 g each, 75 mm long, 62 mm Ø, 20 mm mounting hole spacing, 250 mm leads
- ESCs: BLHeli 40 A (50 A burst), 2S–6S, 5V/3A BEC, bidirectional, programmable

## Key conclusions
- **Go 6S**: rated thrust is at 24 V; 4S gives only ~0.75–1 kg/thruster, 6S ~1.7 kg
- Cap `MOT_THR_MAX` ~90% (full 6S = 25.2 V, slightly over 24 V rating)
- Loaded speed limited by hull speed (~0.9–1 m/s for this size hull); extra thrust shows more on the return

## Battery comparison (cruise ≈ 14 Wh/drop, full throttle 6S ≈ 33 Wh/drop, 80% usable)
| Pack | Weight | Top speed loaded / empty | Drops cruise / full |
|---|---|---|---|
| 4S 5500 LiPo | ~550 g | 0.9–1.1 / 1.5–1.8 m/s | ~4–5 / same |
| 6S 5000 LiPo | ~750 g | 1.2–1.4 / 2+ m/s | ~6 / ~2–3 |
| 6S1P 21700 P42A | ~420 g | 1.15–1.3 / ~2 m/s | ~5 / ~2 |
| 6S2P 21700 P42A (8,400 mAh, ~181 Wh) | ~880 g | 1.2–1.4 / 2+ m/s | ~10 / ~4 |
- Both LiPos (5000+ mAh) likely too long for the 98 mm bay — measure
- 6S2P P42A is ~450–500 g heavier than the stock 10 Ah pack; total upgrade ~750–800 g over stock

## 6S2P sizing
- 4×3 upright brick: ~88–92 × 66–70 × 74–78 mm — fits bay (glue cells, no printed holders; +~10 mm lid for wiring)

## Sourcing (South Africa)
- Molicel P42A (21700, 4200 mAh, 45 A): DIYElectronics (~R209), The Vapery, Vaporworx (~R230), Vanilla Vape
- Akita Custom Batteries (Randburg, 011 704 2429, info@akita.co.za): quoted 6S2P Samsung 30P (6,000 mAh) + 12 A BMS = R2,662 incl VAT
  - Issue: 12 A BMS too small (full throttle ~26 A); they have no 30 A BMS
  - Note: P42A is 45 A per cell — their concern about it was mistaken
  - Fix: ask for **no BMS** (XT60 + 7-pin JST-XH balance lead), or charge-only BMS
- AliExpress best fit: **2× Auline 21700 S70 6S 4500 mAh** (75×64×42 mm, 70 A each) in parallel → ~9,000 mAh, fits bay standing side by side
  - Buy as matched pair, parallel only at equal voltage, XT60 Y-harness; check SA lithium shipping

## ArduPilot Rover setup notes
- Skid steering: `SERVO1/3_FUNCTION = 73/74`, min/trim/max 1000/1500/2000, `MOT_PWM_TYPE = 0`
- ESCs in bidirectional (3D) mode, neutral 1500 µs
- Battery failsafe with RTL: Li-ion ~3.3 V/cell (19.8 V for 6S); set above any BMS cutoff
- Log mAh used per drop to get real drop counts

## Battery level LEDs (plan: options 1 + 3)
- Reuse stock 4 LEDs driven by a small MCU (ATtiny85/Nano/ESP32), divider e.g. 100k/10k, powered from ESC BEC
- Auto-detect 4S/6S at power-up; thresholds per cell: 3 blue ≥3.95, 2 ≥3.80, 1 ≥3.65, red <3.65, flash <3.5 (adjust lower for Li-ion)
- Bypass stock board logic: cut battery feed, isolate LEDs from chip, drive via resistors (150–330 Ω blue, 220–470 Ω red at 5 V)
- Plus Pixhawk battery failsafe as the safety net

## Hull
- Probably fine for now; risks: pod mounting strength under thrust, stern freeboard, ESC heat
- Bath test with ~1 kg ballast + full bait: ≥3 cm freeboard OK, ~2 cm marginal
- Fallback: print hull on K1C (220×220×250 mm) in sections, ASA, epoxy/fibreglass skin

## Next steps
1. Wait for thrusters; bench test with props in water
2. Decide pack: 2× Auline S70 (AliExpress) or no-BMS P42A 6S2P (Akita/DIY)
3. Weigh stock battery; bath/ballast hull test
4. Design printed thruster mounts (20 mm hole spacing) and taller battery lid
5. Configure Rover params + battery failsafe; build LED indicator

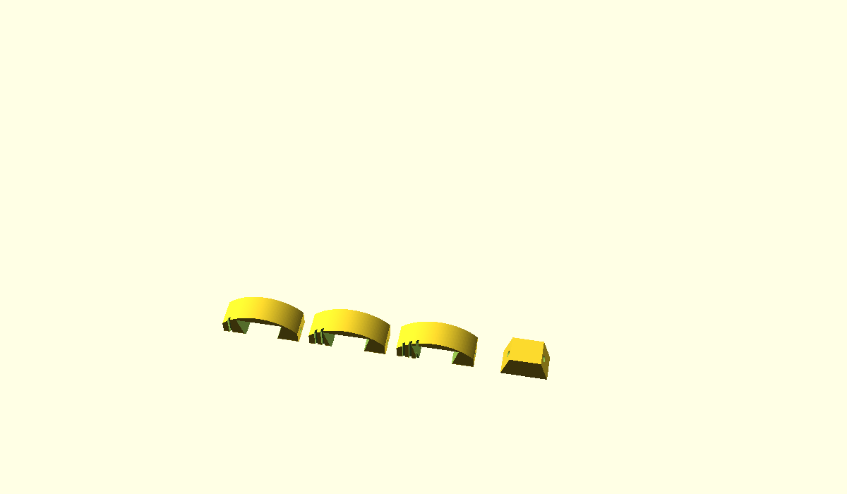
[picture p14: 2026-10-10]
designs/thruster-mount/v2/renders/fit_dovetail_ladder.png

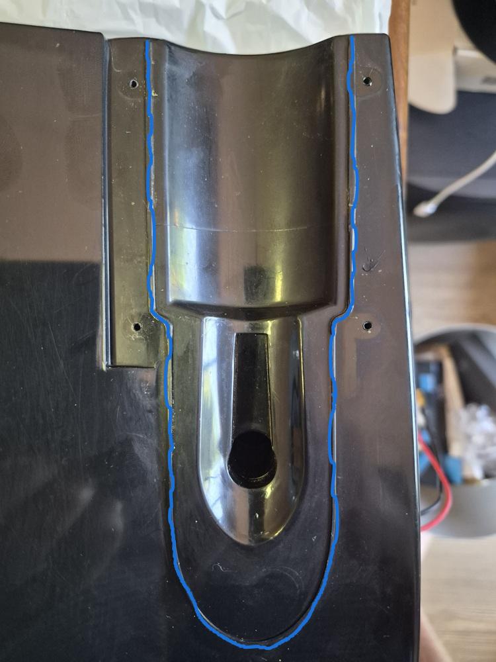
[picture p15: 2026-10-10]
designs/thruster-mount/photos/20261010_ridge_marked_cobus.jpg

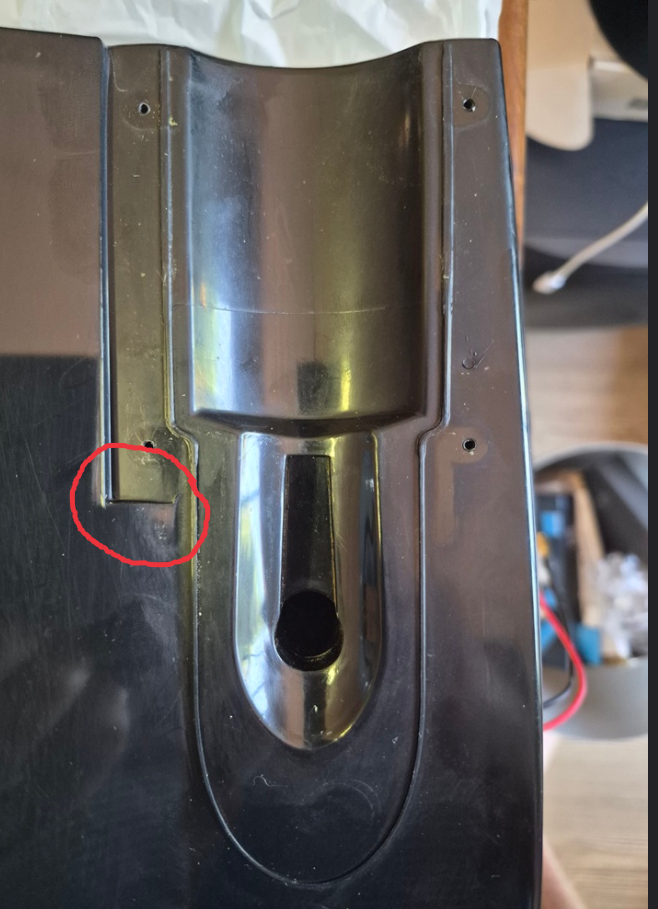
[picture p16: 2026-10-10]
designs/thruster-mount/photos/20261010_catches_corner_cobus.png

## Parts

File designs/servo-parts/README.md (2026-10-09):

# Servo parts

Drawn by Cobus in SketchUp during the upgrade. Added 2026-10-08 from `Servo Parts.stl`.

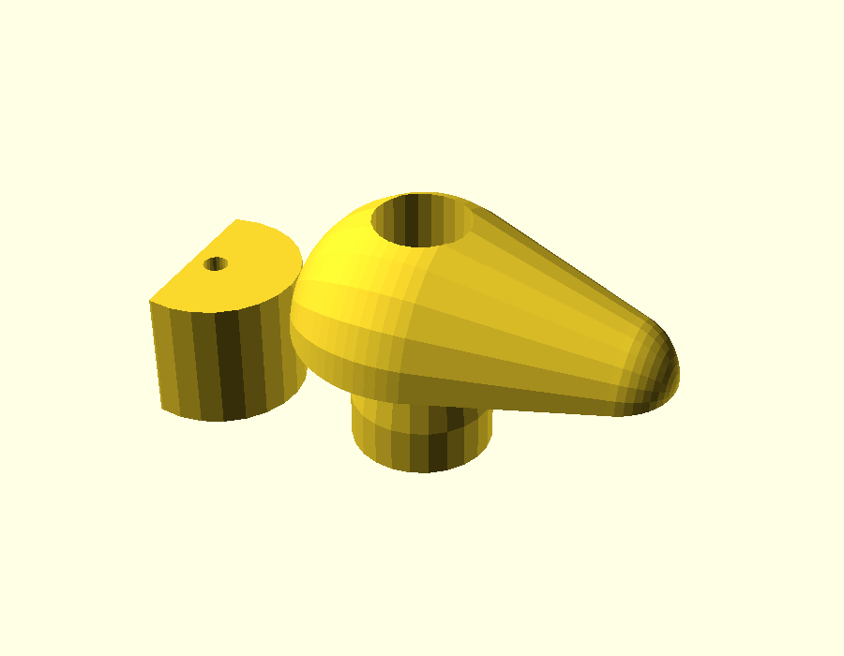
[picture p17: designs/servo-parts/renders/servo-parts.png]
Servo parts


## What it's for

**Servo horn that opens and locks the bait hoppers.** The stock hopper servos were continuous-rotation; they were replaced with normal (positional) **metal-geared servos**, and the stock horn didn't fit the new servos' spline.

Described by Cobus, 2026-10-09. **Printed in eSUN PLA+ and in use.**

## What's in the file

`servo-parts.stl` is a print plate with 2 parts, in millimetres:

| Part | Size (mm) |
|---|---|
| Half-round block with a small hole | 7.1 × 11.0 × 8.4 |
| Teardrop arm with a round boss underneath and a bore through it | 24.0 × 16.0 × 15.4 |

🚨 The mesh has **54 open or doubled edges**, which is common in SketchUp exports. Most slicers repair this on import; if a layer prints oddly, this is the first suspect.

## Source

The SketchUp `.skp` file isn't in the repo yet. Add it here as `servo-parts.skp` so the original can be reopened and changed.

## Changing it

Without the `.skp`, changes are made on this STL in OpenSCAD: adding or cutting features, or scaling. Redrawing it as a parametric `.scad` is the better route if it will keep changing.

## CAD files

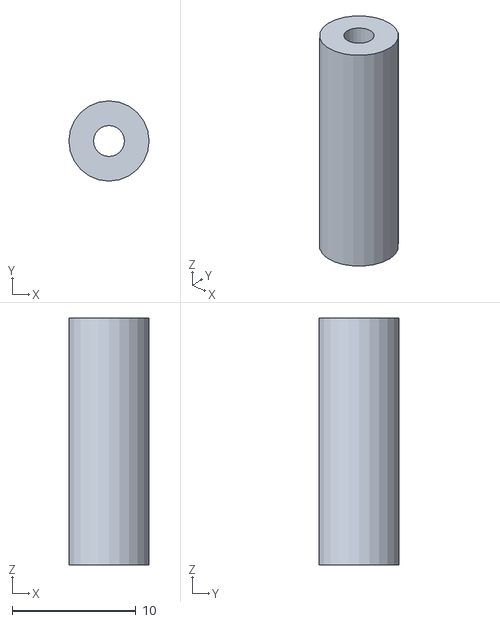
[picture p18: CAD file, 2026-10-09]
designs/cable-holders/receiver-antenna-tube.stl
6.50 x 6.50 x 20.0

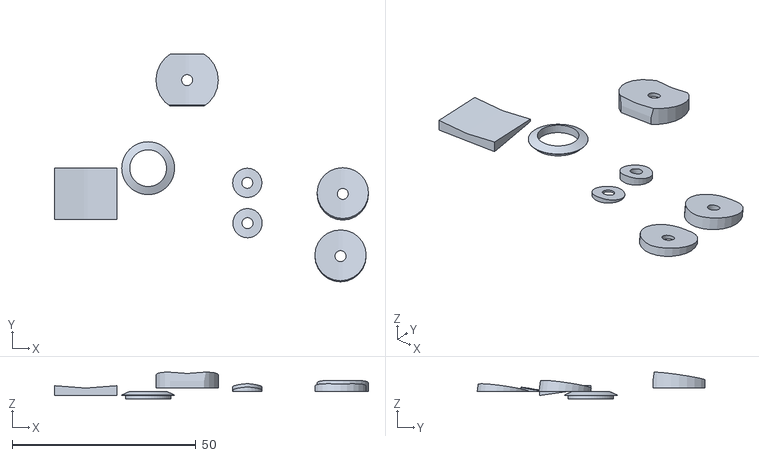
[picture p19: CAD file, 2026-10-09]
designs/gps-antenna-spacer/gps-antenna-spacer.stl
85.5 x 62.0 x 7.33

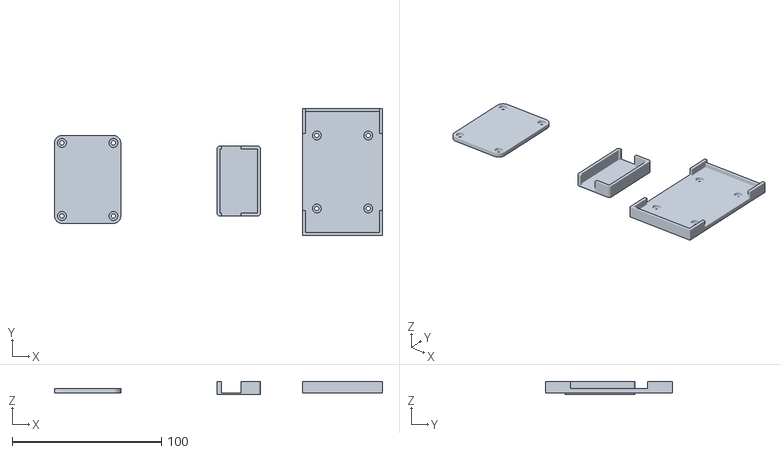
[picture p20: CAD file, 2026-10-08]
designs/pixhawk-bed/pixhawk-bed.stl
220.1 x 85.5 x 9.00

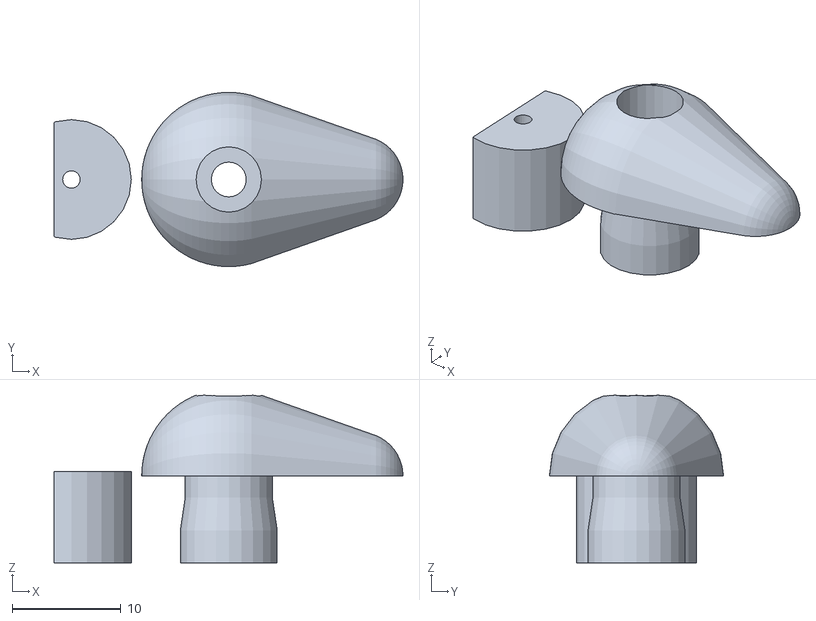
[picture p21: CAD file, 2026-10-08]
designs/servo-parts/servo-parts.stl
32.1 x 16.0 x 15.4

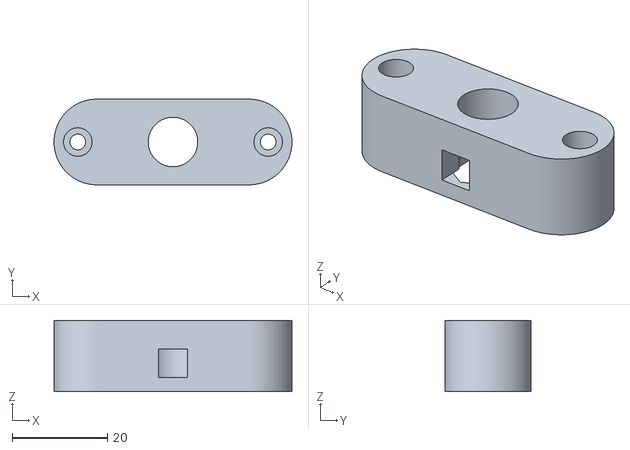
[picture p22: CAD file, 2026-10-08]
designs/thruster-mount/thruster_mount_mount.stl
50.0 x 18.0 x 15.0

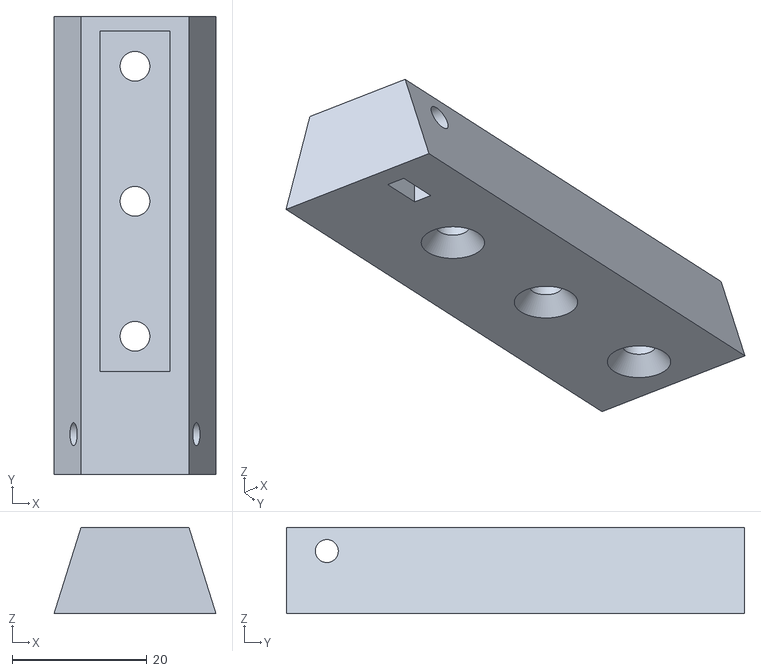
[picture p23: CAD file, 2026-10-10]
designs/thruster-mount/v2/v2_carrier_right.stl
24.0 x 67.9 x 12.8

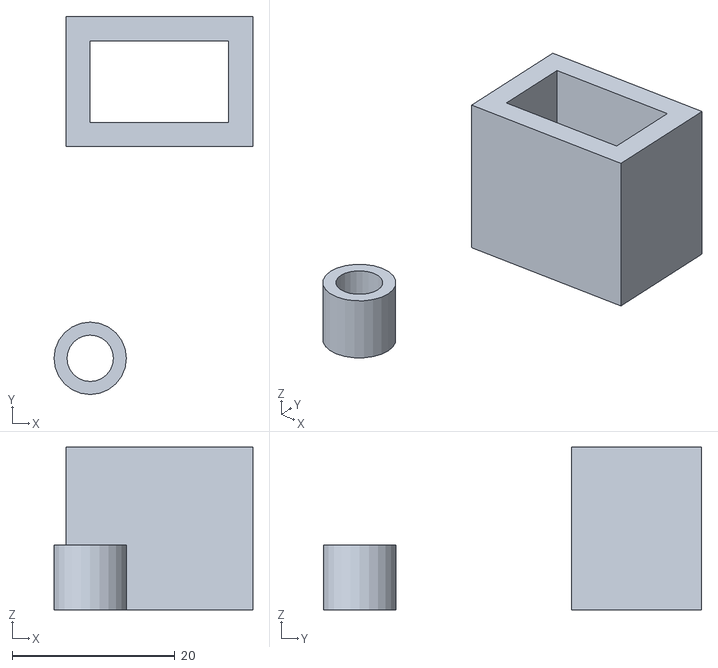
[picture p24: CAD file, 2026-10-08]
designs/cable-holders/cable-holders.stl
24.4 x 46.4 x 20.0

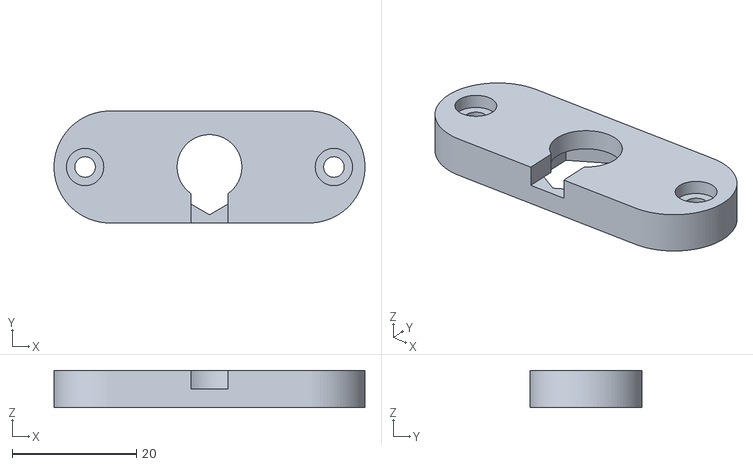
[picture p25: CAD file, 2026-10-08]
designs/thruster-mount/thruster_mount_fit_bottom.stl
50.0 x 18.0 x 6.00

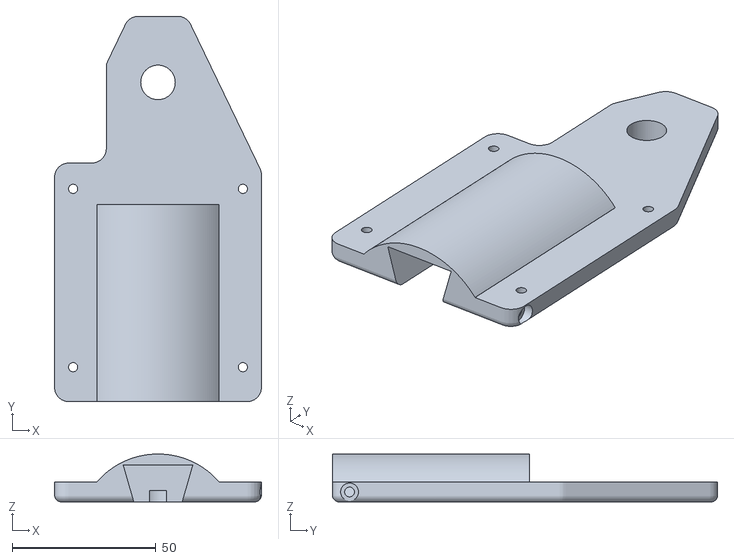
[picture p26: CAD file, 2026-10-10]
designs/thruster-mount/v2/v2_base_right.stl
72.0 x 134.0 x 16.7

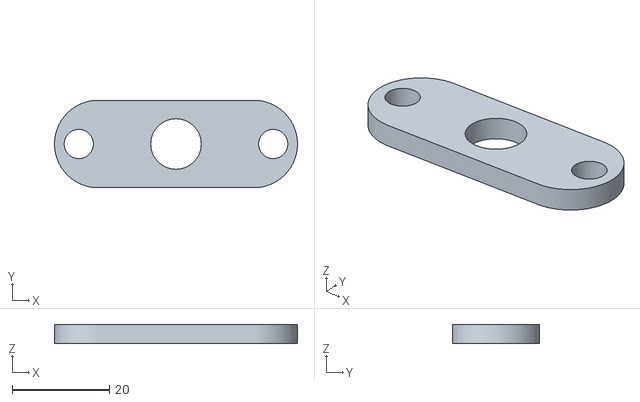
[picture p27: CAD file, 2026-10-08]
designs/thruster-mount/thruster_mount_fit_top.stl
50.0 x 18.0 x 4.00

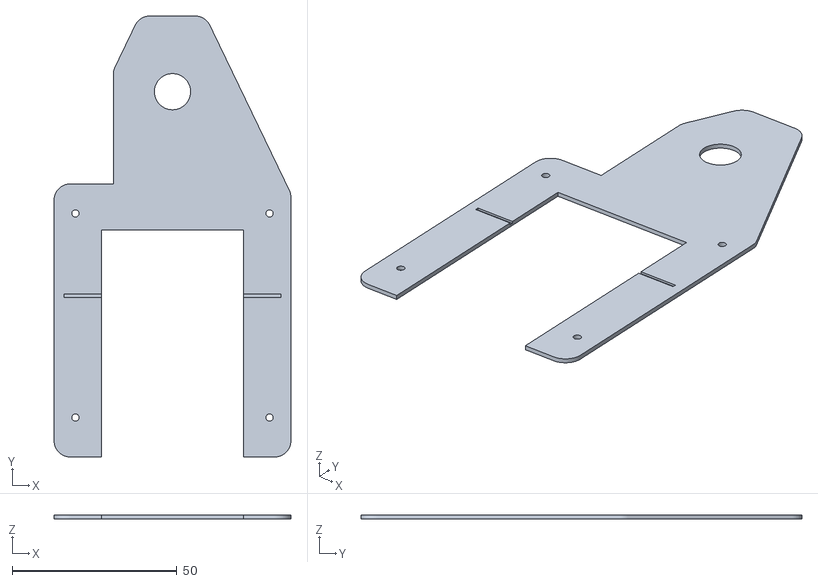
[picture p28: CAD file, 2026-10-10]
designs/thruster-mount/v2/v2_template_right.stl
72.0 x 134.0 x 1.20

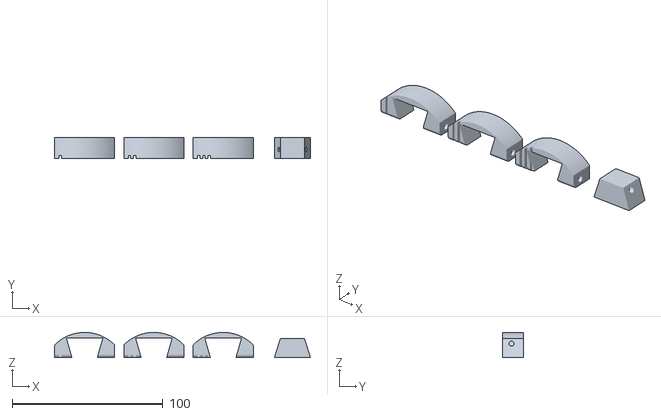
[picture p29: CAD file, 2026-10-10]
designs/thruster-mount/v2/v2_fit_dovetail_ladder_right.stl
170.0 x 14.0 x 16.7

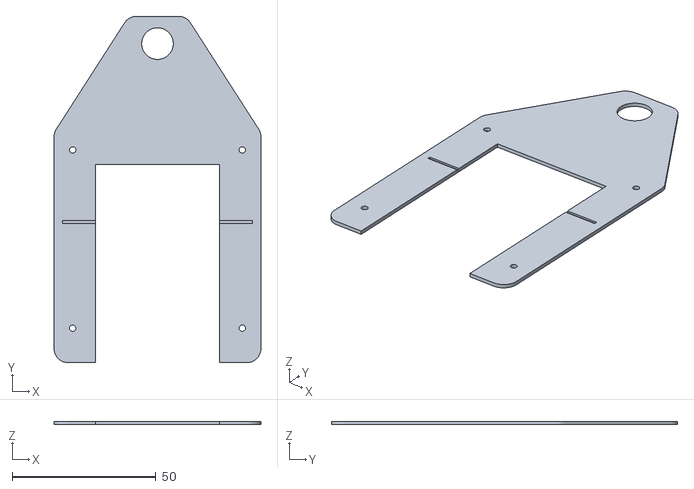
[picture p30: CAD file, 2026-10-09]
designs/thruster-mount/v2/v2_template.stl
72.0 x 120.5 x 1.20

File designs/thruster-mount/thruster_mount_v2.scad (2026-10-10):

// ===========================================================================
// thruster_mount_v2.scad — BASE + CARRIER that hang a 62 mm ducted thruster in
// the D007's moulded motor tunnel, using the hull's 4 EXISTING screw posts
// ---------------------------------------------------------------------------
// WHY v2 (2026-10-09): with the stock pods off, each motor position turned out
// to have a moulded tunnel in the hull bottom (43 wide, 10 deep, 69 long),
// flat 9 mm strips either side, and 4 SOLID posts inside (6.2 dia, 14.5 tall)
// that the stock motor shield screwed into from outside (2 mm pilot holes,
// ST2 x 7). The posts are closed, so the hull is already sealed there: no new
// holes, no through-bolts, no backing plate. v1 (a pylon on a lamp tube
// through the old post hole) is shelved.
//
// TWO PARTS, because the thruster's oval openings are closed: nothing can
// reach the foot screws from below, and the duct covers the post screws.
//
//   inside hull    posts (existing)
//   ═══════╪═══════╭─────╮═══════╪═══════  hull, tunnel in the middle
//      ST2.9 x 13  │BASE │  ST2.9 x 13     BASE: fills the tunnel, screws to
//   ───────┴───────┤╲   ╱├───────┴───────  the 4 posts, DROP below the hull
//                  │CARRIER               CARRIER: dovetail bar, slides in
//                  └──┬──┘                 from the stern, foot bolted in
//                  ╭──┴───────╮            with 3 x M4 from its top
//                  │ thruster │
//
//   1  Screw the BASE to the 4 posts, from outside, thruster OFF.
//   2  On the bench, bolt the thruster's foot into the CARRIER: 3 x M4
//      countersunk, down through the carrier's top. Tap the foot's 3 mm holes
//      M4 (3.3 mm drill), to their EXISTING depth. Never drill through: the
//      foot sits on the duct and a bolt end would hit the propeller.
//   3  Slide the carrier into the base from the stern until it stops (forward
//      thrust pushes it into the stop). Fit the side LOCK screw, M3 x 40, from
//      the outboard side; its nut sits in a slot in the carrier.
//
// LOADS: about 1.7 kg thrust per side. With the thrust line ~45 mm below the
// hull and the posts 62 mm apart, each post screw sees only ~6 N. The screws
// are there for KNOCKS (rocks, landing it on the bank), which is why they are
// 2.9 x 13, not the shield's 2 x 7: grip depth in the post is what counts.
// Bed the base in thickened epoxy (or ABS cement, the hull is ABS) to take a
// knock off the screws.
//
// 🚨 VALUES MARKED "VERIFY" ARE NOT MEASURED. Print part = "template" first
// (lay it on the hull: do the 4 holes land on the 4 pilot holes?) and
// "fit_dovetail" (does the carrier slide in with a light push?).
//
//   part = "base" | "carrier" | "template" | "fit_dovetail" | "all" | "none"
//          ("none" draws nothing: for check scripts that include this file)
//   side = "right" | "left"  the lock screw goes in from the OUTBOARD side, so
//          print one base + one carrier of each. "right" = screw at +X.
//
// Print: ABS or ASA (not PLA: sun + water), 4+ walls, 40 %+ infill. Both parts
// are already laid out for printing: the base on its flat underside, the
// carrier on its flat top. Units: mm.
// Model axes (part = "all"): X across the boat (0 = tunnel centreline),
// Y forward from the transom (0 = transom edge), Z up (0 = hull bottom).
// ===========================================================================

part = "all";
side = "right";

/* [Hull: Cobus's measurements, 2026-10-09 (designs/thruster-mount/measure)] */
tun_w   = 43;      // #4 / #8 tunnel width
tun_d   = 10;      // #9 tunnel depth at the transom
tun_l   = 69;      // #5 transom edge to where the tunnel steps up
strip_w = 9;       // #6 flat strip beside the tunnel
post_x  = 59 / 2;  // #2 posts 59 apart across
post_y1 = 12;      // #20 transom edge to the first pair
post_pitch = 62;   // #3 first pair to second pair
hull_t  = 3;       // #13
wire_y  = 111;     // #7 transom edge to the wire hole's centre
wire_d  = 11;      // VERIFY: the old post hole, ~11 mm
// The small rail across the tunnel (2 wide, 0.5 high, check "A"). Position is
// read off photo 1 by scale, so the groove is cut generously wide.
// Cobus, 2026-10-09: no groove needed. The rail is 0.5 high and the epoxy
// bed (bed_gap) takes it up; sand it down if the base rocks on a dry fit.
rail_groove = false;
rail_y  = 49;      // VERIFY: transom edge to the rail
rail_gw = 5;       // groove width (rail 2 + slack for the estimate)
rail_gd = 1.0;     // groove depth (rail 0.5 + slack)
// The strips are shallow POCKETS. On the INBOARD side of the tunnel (away
// from the hull's edge) the hull steps 4 mm proud at the strip's forward end;
// the template's corner caught on it (Cobus, 2026-10-10, measure/ #24-26).
// The outboard strip runs to the hull edge: no step there.
step_y     = 84;   // #25 transom edge to the step
step_h     = 4;    // #24 how far the hull forward of it stands proud
step_x0    = 18;   // VERIFY: where the raised area starts across. It begins at
                   // the tunnel's frame line (~21.5); 18 leaves a margin
step_clear = 0.5;  // (unused since the cut-out; kept for a relief variant)

/* [Thruster: measured] */
duct_l    = 75;    // spec
duct_od   = 74;    // #14 in the middle (67 at the edges)
foot_w    = 10;    // #16
foot_l    = 50;    // #17
hole1     = 14.5;  // #18 duct's front edge to the first foot hole
hole_pitch = 20;   // the three foot holes, front to back
// #15: the foot stands 8.5 above the duct at its ends but only 7 in the
// middle, because the duct bulges (67 -> 74). So the foot can only sink 7 mm
// before the duct's bulge touches the carrier; its ends stay 1.5 mm proud.
foot_sink = 7.0;
duct_aft  = 0;     // the duct's back edge, from the transom (0 = flush)

/* [Mount] */
drop     = 7;      // base underside below the hull = duct top below the hull.
                   // Clearance for water to reach the intake, and the depth
                   // the side lock screw and post-screw heads need.
wing     = 36;     // base half-width: posts at 29.5 + head pocket + wall
bed_gap  = 0.3;    // base top this far off the tunnel roof, for the epoxy
corner_r = 5;      // outline corners, seen from below
edge_r   = 2.5;    // round on the base's bottom edge, all the way round (the
                   // top edge stays square: it beds flat on the hull)

/* [Post screws: ST2.9 x 13 stainless pan head] */
ps_clear = 3.2;
ps_head  = 6.2;    // pan head ~5.6
ps_sink  = 2.0;    // head sunk this far into the base underside
// pilot: open the hull's 2 mm holes to 2.4 mm, ~12 mm deep (hull + post =
// 17.5, so 12 leaves the post's closed top intact). Try one post first.

/* [Carrier: dovetail bar] */
// The walls' slope sets how far the carrier SINKS for a given side gap:
// drop = clearance / ((car_tw - car_bw) / 2 / car_h). The first test print
// (18 / 22, 0.3 clearance) had walls only ~9 deg off vertical, so 0.3 a side
// let it sink ~2 mm: "play all round" (Cobus, 2026-10-10, PLA). 16 / 24
// doubles the slope; with 0.15 clearance the drop is ~0.5 mm.
car_bw   = 16;     // width at the bottom (open face); foot pocket 10.4 + 2.8 walls
car_tw   = 24;     // width at the top: wider, so it cannot drop out
min_skin = 1.2;    // least base plastic left above the carrier, under the roof
dv_clear = 0.10;   // slide clearance each side. Measured 2026-10-10: of the ABS
                   // ladder (0.10 / 0.15 / 0.20), 0.10 fit best with no wobble
foot_clear = 0.2;
// M4 countersunk into the foot
m4_clear = 4.4;
m4_csk_d = 8.4;
m4_csk_h = 2.4;

/* [Side lock screw: M3 x 40 + nut] */
lock_y   = 6;      // in the 15 mm at the aft end where the carrier has no foot
lock_z   = -drop / 2;
lock_d   = 3.4;
lock_head = 6.2;
lock_cb  = 3.0;    // head counterbore into the base's side face
nut_af   = 5.5;  nut_t = 2.4;  nut_x = -4;   // nut slot, past the centreline

/* [Wire cover] */
cover_end_w = 10;  // half-width where the cover ends
cover_past  = 23;  // wire-hole centre to the cover's front end. Cobus, 2026-10-10:
                   // reach far enough to cover the old mounting hole forward of it
groove_w = 6;      // wire channel in the base underside, carrier -> wire hole
groove_d = 4;

$fn = 64;
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

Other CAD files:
designs/thruster-mount/v2/v2_base_left.stl
designs/thruster-mount/v2/v2_template_left.stl
designs/thruster-mount/v2/v2_carrier_left.stl
designs/thruster-mount/thruster_mount.scad

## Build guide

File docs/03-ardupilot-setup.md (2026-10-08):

# ArduPilot Rover setup

Planned settings for the brushless upgrade. Nothing here has been applied yet.

## Skid steering

| Parameter | Value | Note |
|---|---|---|
| `SERVO1_FUNCTION` | 73 | Throttle left |
| `SERVO3_FUNCTION` | 74 | Throttle right |
| `SERVO1_MIN` / `TRIM` / `MAX` | 1000 / 1500 / 2000 | Same for `SERVO3_*` |
| `MOT_PWM_TYPE` | 0 | Normal PWM |
| `MOT_THR_MAX` | about 90 | A full 6S pack (25.2 V) is slightly over the thrusters' 24 V rating |

Set both ESCs to bidirectional (3D) mode, with neutral at 1500 µs.

## Power module (Holybro PM06)

Values are from [Holybro's PM06 V2 specs](https://www.getfpv.com/electronics/autopilot-systems/pm06-14s-power-module.html). Check them against the version on hand, and calibrate against a multimeter and a known charge.

| Parameter | Value |
|---|---|
| `BATT_MONITOR` | 4 (analog voltage and current) |
| `BATT_VOLT_MULT` | 18.182 |
| `BATT_AMP_PERVLT` | 36.364 |

## Battery failsafe

- Return home (RTL) on low battery. For Li-ion, about **3.3 V per cell, 19.8 V for 6S**.
- Set it above any BMS cut-off, so the boat starts home before the BMS disconnects the pack.
- Log the mAh used per drop to get real drop counts per charge.

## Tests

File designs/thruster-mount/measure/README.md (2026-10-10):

# Measurements for thruster mount v2

Each number on the pictures is one measurement. Fill in the **mm** column (or just send the numbers back in chat), measuring **one side**. If the other side looks different, measure it too.

| Picture | |
|---|---|
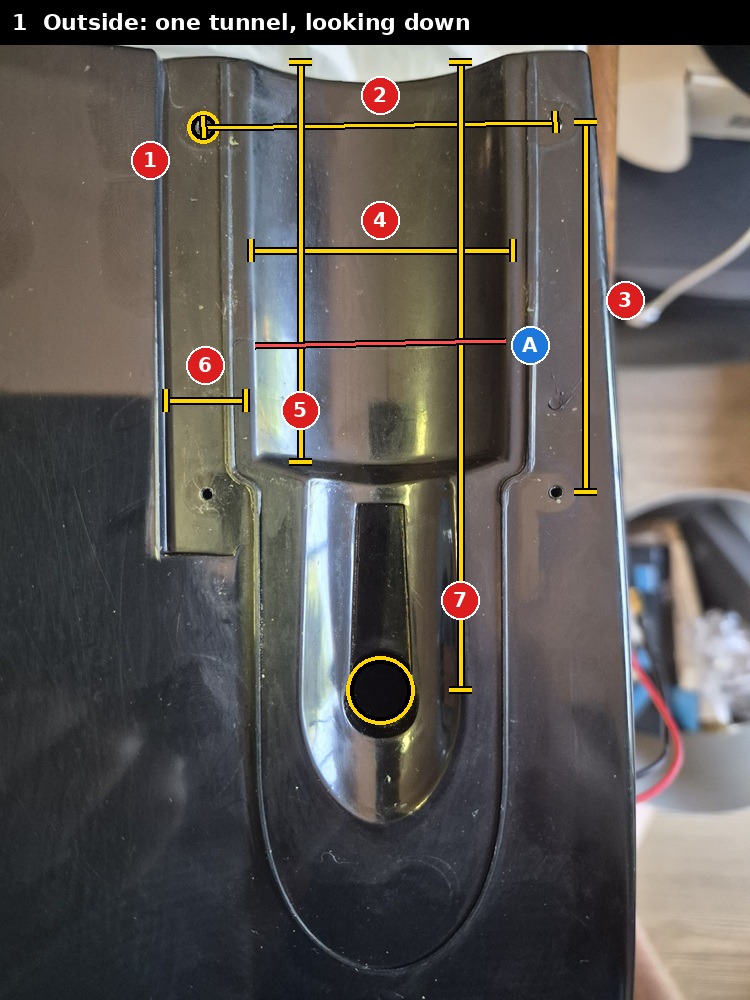
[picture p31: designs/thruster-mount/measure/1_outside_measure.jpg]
| [1 Outside](1_outside_measure.jpg) |  |
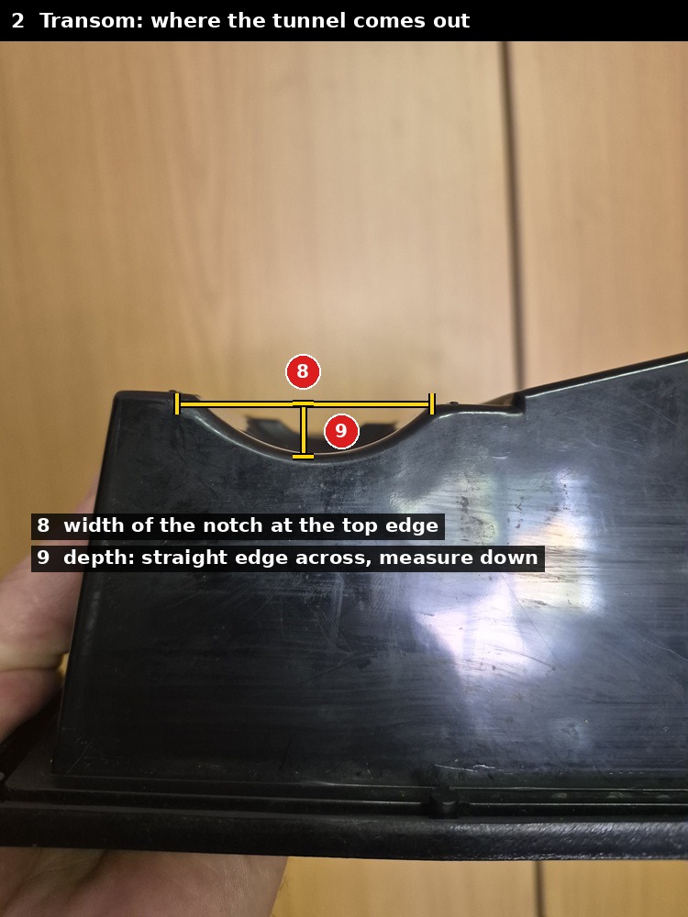
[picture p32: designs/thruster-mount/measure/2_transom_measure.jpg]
| [2 Transom](2_transom_measure.jpg) |  |
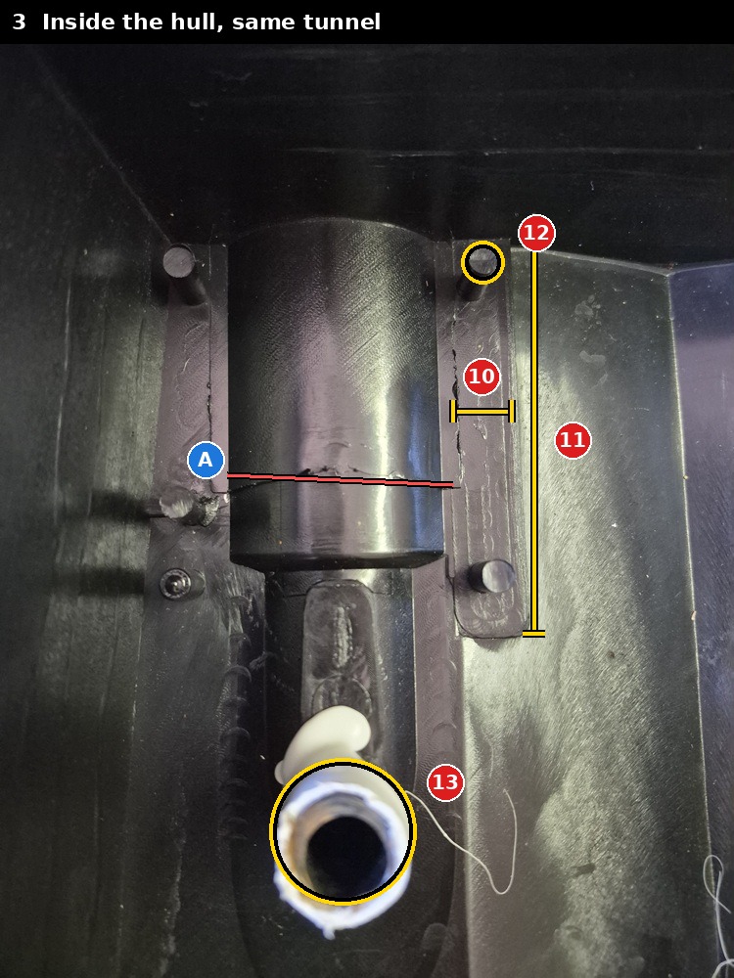
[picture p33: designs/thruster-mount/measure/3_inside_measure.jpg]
| [3 Inside](3_inside_measure.jpg) |  |
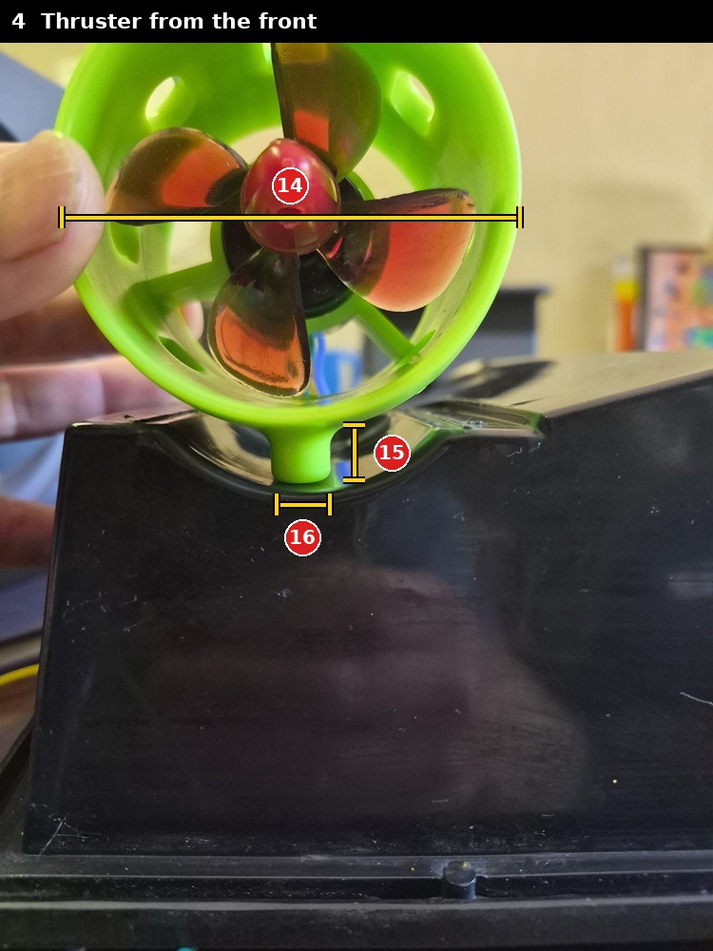
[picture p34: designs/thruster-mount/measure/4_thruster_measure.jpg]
| [4 Thruster front](4_thruster_measure.jpg) |  |
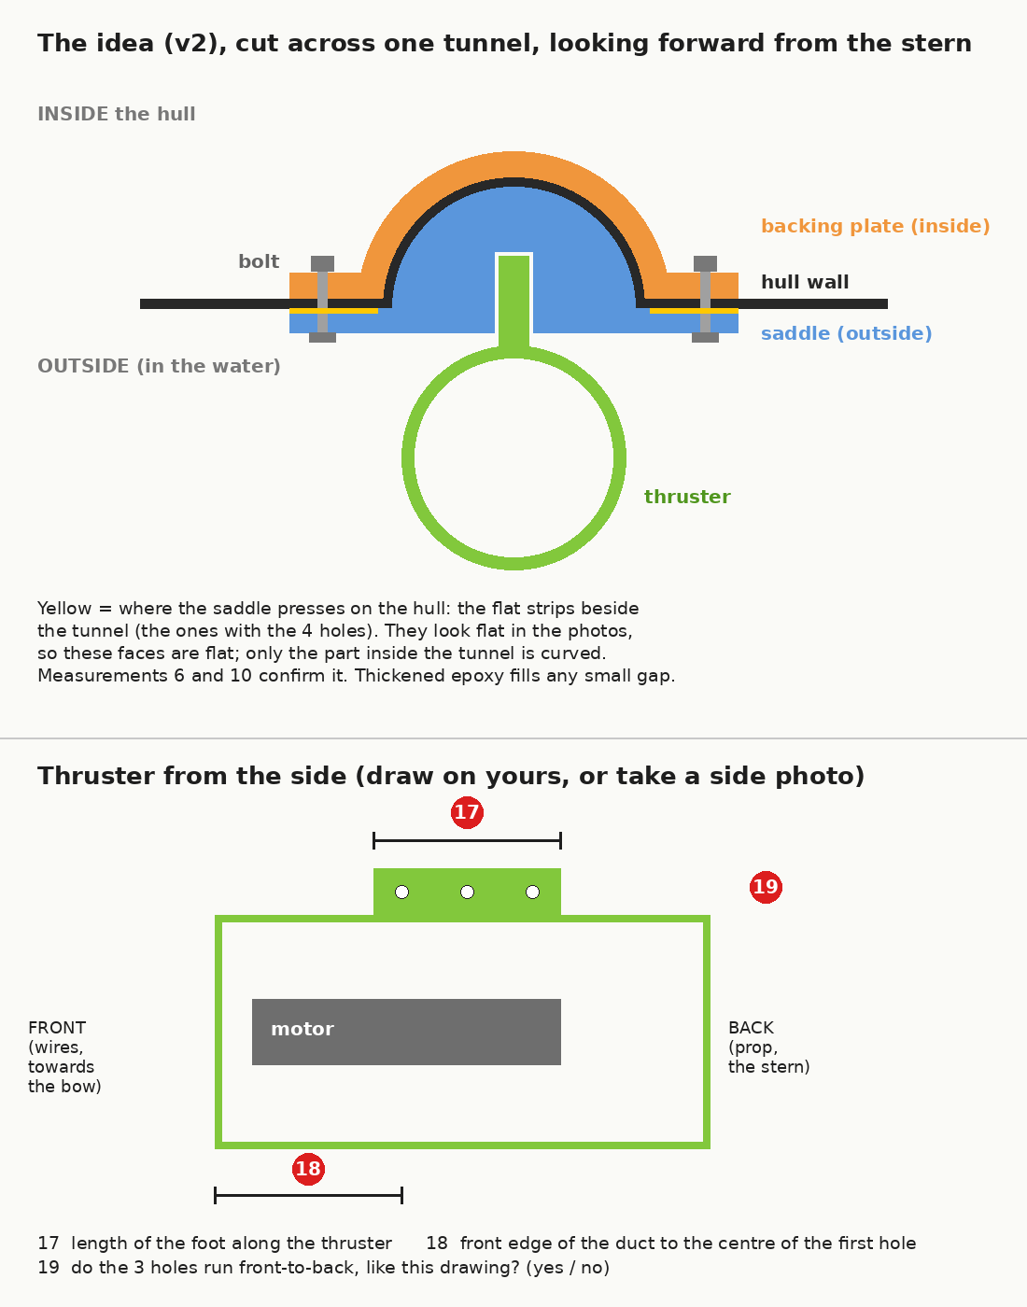
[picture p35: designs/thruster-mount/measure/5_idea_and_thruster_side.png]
| [5 The idea + thruster side](5_idea_and_thruster_side.png) |  |

| # | Picture | What to measure | mm |
|---|---|---|---|
| 1 | 1 | Diameter of one of the 4 small holes | 2 |
| 2 | 1 | Centre to centre, across the tunnel (top-left hole to top-right hole) | 59 |
| 3 | 1 | Centre to centre, along the tunnel (top-right hole to bottom-right hole) | 62 |
| 4 | 1 | Width of the tunnel, edge to edge where it meets the flat strips | 43 |
| 5 | 1 | Length of the tunnel, transom edge to where it steps up | 69 |
| 6 | 1 | Width of one flat strip beside the tunnel. **Is it flat?** Lay a ruler on it | 9 It is flat|
| 7 | 1 | Transom edge to the centre of the wire hole | 111 |
| 8 | 2 | Width of the notch at the top edge of the transom | 43 |
| 9 | 2 | Depth of the notch: lay a straight edge across, measure down to the bottom | 10 |
| 10 | 3 | Width of one flat strip inside, beside the hump | 11 |
| 11 | 3 | Length of that strip | 84 |
| 12 | 3 | One pin: its diameter, and is it **metal or plastic**? | 11.2 plastic |
| 13 | 3 | Hull wall thickness at the wire hole (take the white tube out first) | 3 |
| 14 | 4 | Outside diameter of the duct | 67 on edge and 74 in the middle |
| 15 | 4 | Height of the foot: bottom of the duct to the bottom of the foot | 8,5 on foot edge and 7 in middle of foot |
| 16 | 4 | Width of the foot | 10 |
| 17 | 5 | Length of the foot, front to back | 50 |
| 18 | 5 | Front edge of the duct to the centre of the first of the 3 holes | 14.5 |
| 19 | 5 | Do the 3 holes run front to back? (yes / no) | yes |

| 20 | 7 | Transom edge to the centre of the first two holes | 12 |
| 21 | 6 | Diameter of one post inside | 6.1 - 6.2 |
| 22 | 6 | Height of that post above the flat strip. **Is its top closed (solid)?** | 14.5 it is closed, solid|
| 23 | 6 | The screw beside the post: what size, and what does it hold? | that is actually a post where the one screw goes in. On that image I circled a post that is not used. The blue post is also only on the one side of the hull. The other side does not have this post.|

Follow-up pictures (2026-10-09): [6 posts inside](6_followup_inside.jpg), [7 where the holes start](7_followup_outside.jpg). The v2 idea drawn to scale from 1-19: [8 v2 to scale](8_v2_to_scale.png). Plan view from below: [9 v2 plan](9_v2_plan.png). The two-part saddle (base + sliding carrier), needed because the duct's oval openings are closed: [10 v2 two-part](10_v2_two_part.png). Template test result (2026-10-10): all 4 holes line up; one corner catches on a step: [11 the step](11_corner_step.jpg).

| 24 | 11 | Height of the step at the forward end of the strip (the corner the template caught on, 2026-10-10) | 4 |
| 25 | 11 | Transom edge to that step | 84 |
| 26 | 11 | Is there the same step on the other side? (yes / no) | no |

| 27 | 12 | Dovetail test piece in the notch (2026-10-10, ~1 mm gap on the curve): press each wing down. Does it **rock**, or sit solid? | |
| 28 | 12 | Torch from behind: is there light **under the wings**? | |
| 29 | 12 | Gap at G1 (slope) and G2 (bottom): the largest drill-bit shank that slides in | |
| 30 | — | The carrier: light push to slide in? Does not fall out? M3 nut drops into its slot? | |

**Also check A** (the blue A on pictures 1 and 3): is that line across the tunnel a **crack**, or left-over glue? Picture 3 is just some residual plastic probably from the mold is was created from. Picture 1 the blue A is on what looks like a kind of a rail 2mm wide and 0.5mm height that runs accross that pattern

## Files

- `annotate.py` draws the lines on copies of the photos in `../photos/` (pictures 1-4, 6, 7). `sketch.py` draws picture 5; `sketch_v2.py`, `plan_v2.py` and `sketch_v2b.py` draw pictures 8, 9 and 10 to scale from the measurements. Re-run after any change.

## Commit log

2026-10-08 Start the D007 upgrade record
    Stock specs and the Pixhawk conversion, the 6S brushless upgrade plan
    (thrusters, ESCs, PM06, battery options, sourcing), Rover parameters,
    the LED gauge plan and the planned printed parts. HANDOVER.md is the
    state doc. The earlier chat export is kept in docs/sources.
2026-10-08 Add the thruster mount, version 1
    A printed pylon that hangs each 62 mm thruster from the stock motor-post
    hole on a steel M10 x 1 hollow lamp tube, which also carries the wires.
    It bolts to the thruster's outer two holes (40 mm apart; the middle one
    is under the tube). Parametric OpenSCAD with asserts, two fit-test
    slices, STLs and renders. Not yet printed: the VERIFY values in the
    .scad are assumptions.
    [thruster_mount.scad, thruster_mount_fit_bottom.stl, thruster_mount_fit_top.stl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]
2026-10-08 Add the SketchUp-drawn parts as STLs
    Cable holders, servo parts, Pixhawk bed and GPS antenna spacer, each in
    its own folder with a render and a README listing every piece and its
    size. What each part is for is not recorded yet, and the .skp sources
    are not in the repo yet.
    [cable-holders.stl, gps-antenna-spacer.stl, pixhawk-bed.stl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]
2026-10-09 Record what the SketchUp parts are for; move the antenna tube
    Each part's README now says what it does, that it's printed and in use,
    and its material: eSUN PLA+, except the GPS spacers in solid TPU-95.
    The receiver antenna tube was on the GPS spacer plate; it is now its own
    STL in cable-holders/, with its triangles copied unchanged. docs/01
    records the servo swap, the GPS antenna position, the Pixhawk bed and
    the cable holders.
    [gps-antenna-spacer.stl, receiver-antenna-tube.stl]
2026-10-09 Thruster mount v2: hull photos, measurements and concept drawings
    Photos of the hull with the stock pods off, numbered measurement
    pictures (Cobus's measurements 1-23 filled in, and his own mark on
    picture 6), and to-scale drawings of v2: a base screwed to the hull's
    four existing posts and a carrier that holds the thruster and slides in
    from the stern. The v1 lamp-tube pylon is shelved.
2026-10-09 Add thruster mount v2: base on the hull's posts + sliding carrier
    The base fills the moulded tunnel and screws into the hull's four
    existing posts (ST2.9 x 13), 7 mm below the hull, with rounded edges
    and a cover over the motor wires. The carrier holds the thruster's foot
    (3 x M4 into the tapped foot), slides in from the stern on a dovetail
    and is locked by one M3 x 40 from the outboard side, so there are left
    and right versions. Includes a hull template and a dovetail fit test.
    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
    [thruster_mount_v2.scad, v2_base_left.stl, v2_base_right.stl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]
2026-10-10 Thruster mount v2: step cut-out, steeper dovetail, clearance ladder
    From the first test prints (2026-10-10):
    - Template: all 4 holes line up. One corner caught on a 4 mm step on
    the inboard side, 84 mm from the transom; the base is now cut away
    there (no cover: less drag, no trapped water) and the template is
    notched, so templates come in left and right versions.
    - The ~1 mm gap on the curve came from a moulding ridge round the mount
    area; the README now says to shave it flush first.
    - The carrier was loose: the dovetail walls were ~9 deg off vertical,
    so 0.3 mm clearance let it sink ~2 mm. Now 16/24 mm at 0.15 mm
    (~0.5 mm), and the fit test is a 0.10/0.15/0.20 clearance ladder.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
    [thruster_mount_v2.scad, v2_base_left.stl, v2_base_right.stl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]
2026-10-10 Thruster mount v2: 0.10 dovetail clearance, longer wire cover
    - dv_clear 0.15 -> 0.10: the ABS clearance ladder fit best at 0.10, no wobble
    - New cover_past = 23: the wire cover runs 23 mm past the wire hole's centre
    (was ~9.5) to cover the hull's old mounting hole
    - Base, carrier and template STLs (left + right) and renders re-exported
    - HANDOVER: ridge shaved, template reprint fits, other tunnel has the same
    inboard step; next is a PLA+ mock-up of the right side
    Claude-Session: https://claude.ai/code/session_011yxWbDmdvoyar1Y3G6ZXR3
    [thruster_mount_v2.scad, v2_base_left.stl, v2_base_right.stl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]
2026-10-11 Thruster mount v2: lock for M3 x 30 + Nyloc, screw choices
    - No stainless M3 x 40 to be found in South Africa, so the lock is redrawn
    for a stainless M3 x 30 (Xtrude 3D): new lock_l, nut slot moved 4.5 mm
    outboard of the carrier's centre, head sunk 4 mm
    - Nyloc nut (4 mm) instead of Loctite, which can stress-crack ABS
    - Nut slot is now the nut's corner width: it drops in flat side down and
    sits centred on the screw (corner-down sat it 0.3 mm high); the floor
    stops it turning
    - Asserts: screw length matches the slot, slot wall to the carrier's side
    and aft end
    - New picture v2/renders/lock_section.png; base and carrier STLs re-exported
    - README/HANDOVER: ST2.9 x 13 stays for the pos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
2026-10-12 Round the carrier's aft bottom edge to match the base
    The carrier's stern end was left square while the base's bottom edge is
    rounded 2.5 mm; the round now runs straight across the slot. Both carrier
    STLs re-exported, with a labelled render.
    Also notes the measured foot-hole depth (10.5 mm, fine for the M4 x 12)
    and that the hopper servo holes already have an O-ring that still leaks.
    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
2026-10-12 Re-render the carrier and assembly pictures with the rounded aft edge
    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
2026-10-14 Battery and PM06 V1 set up: voltage calibrated, RTL failsafe
    Akita 6S2P Li-ion 6,000 mAh with no BMS, so the Pixhawk failsafe is the
    only over-discharge protection. BATT_VOLT_MULT calibrated to 10.930 for the
    PM06 V1 (the V2 value read 40.49 V against 24.34 V on the meter); current
    still uncalibrated. RTL on low (3.3 V/cell or 25%) and critical (3.1 V/cell
    or 15%), sag-compensated; no arming below 3.6 V/cell. Mission Planner now
    runs on the Ubuntu VM over the SiK radio.
    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
2026-10-14 Battery: voltage-only failsafes, cell specs and charging
    The boat is switched off between drops and ArduPilot's mAh count starts
    from zero at every power-up, so BATT_LOW_MAH / BATT_CRT_MAH are now 0 and
    the failsafes go on voltage alone (sag-compensated). Adds the cells
    (taken as Samsung INR18650-30Q), the charging routine, the 30 A pack
    limit, where the 36.364 current figure comes from, and how to read and
    calibrate mAh used from the Quick tab and the DataFlash logs.
    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
2026-10-15 LED: document the NeoPixel on AUX 5 (WS2812D, NeoPixelRGB)
    Wiring: 330 ohm in the data line at DIN, VDD fed through a diode so the
    Pixhawk's 3.3 V data counts as high (straight 5 V did not work). The
    WS2812D takes RGB order, so NTF_LED_TYPES uses NeoPixelRGB (bit 18,
    Rover 4.5+) instead of NeoPixel; green now shows green.
    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
2026-10-15 Battery gauge: plan the home-made replacement, parts ordered
    The stock gauge is resin-potted with unmarked chips, so it is replaced
    by an ESP32-C3 Zero perfboard driving 4 x 3 mm LEDs at the hull's 5 mm
    hole pitch. Records the parts list, the 50 x 35 mm space with the LEDs at
    the top edge, and a labelled photo of the old board.
    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
2026-10-16 GPS spacer: WS2812D LED mount replaces the ring
    Cobus's redesign for the WS2812D status LED, printed in TPU-95.
    Measurements, a labelled picture and his marked screenshot added.
    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
2026-10-16 Wire grommet, voltage-only battery monitoring, parameter backup
    - TPU-95 wire grommet for the thruster wire holes (slit wire holes for
    the bullet connectors). Two test-fit ladders: body 12.0, wires 2.5.
    - ESC calibration not needed (Motor Test ran both ways on defaults).
    - Current sensor reads no signal (step test); Cobus chose not to fix it:
    BATT_MONITOR 3, BATT_FS_VOLTSRC 0. BATT_CRT_VOLT found at 0, reset to
    18.6. ARMING_REQUIRE 0 kept on purpose.
    - Full parameter backup read over MAVLink: params/2026-10-16.param.
    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
2026-10-16 MOT_THR_MAX 90 (was 100)
    A full 6S pack is slightly over the thrusters' 24 V rating.
    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
2026-10-18 Battery gauge: stacked LED strip + driver board + C3 Zero, built and calibrated
    - Layout, wiring and stack pictures (docs/images, generators in docs/images/src)
    - Firmware firmware/battery-gauge: 4-LED bar, 2S/4S/6S detect, cal command;
    re-detects the cell count when a pack is swapped on USB
    - Divider top resistor 330k (was 220k): a wrong low-value resistor in the
    220k's place put the full pack on GP3 and killed the first C3. Added the
    "O5 reads ~0.74 V before connecting GP3" bench step
    - Bench test 2026-10-18: 4S 16.19 V read 16.21 V; 6S2P calibrated at
    24.32 V (ratio 34.1963)
    - Nyloc nuts fitted, CH3 back on J2
2026-10-19 HANDOVER: gauge installed and working; switch stuck-on watch item
2026-10-19 PM06 current: radio interference diagnosed; display-only amps, voltage-based battery %
    - The false current at rest is the 1 W SiK radio getting into the PM06
    (steady 0.6 A at TXPOWER 2; a 10k/100n filter and grounded foil did not
    help). Corrects the old "adapter pin 3" note. Radio kept at TXPOWER 11.
    - BATT_MONITOR 4 (amps display only), BATT_AMP_OFFSET 0; failsafes still
    voltage-only
    - pixhawk-scripts/batt_volt_pct.lua: battery % from smoothed voltage on a
    Li-ion curve matching the hull gauge (SCR_ENABLE 1, SCR_HEAP_SIZE 24576,
    BATT_CAPACITY 6000)
    - params/2026-10-19.param backup (897 params)
2026-10-19 QGroundControl: Fly View actions (lights relay, hopper drop/lock) + README
2026-10-19 Pool run notes, live recorder for the next run, logging-broken watch item
    - HANDOVER 9: thrusters suck air above Futaba 95; Futaba end points don't
    limit phone/Auto driving, MOT_THR_MAX clips in all modes; plan a fixed
    MOT_THR_MAX from a live-recorded pool run
    - HANDOVER 10: no usable log since 2026-10-16 (log 3 = 0 bytes)
    - tools/live_record.py: 10 Hz pitch / outputs / RC / speed / volts / amps
    to CSV through the MAVProxy relay
    Claude-Session: https://claude.ai/code/session_01BHfxXWAXGngA6DJ7qTZgHv
2026-10-20 Pool runs: MOT_THR_MAX 50 + MOT_SLEWRATE 200, hull-speed findings, charts
    - Live-recorded pool runs (data/): past ~1 m/s the hull climbs its bow
    wave; loaded the nose reaches 31 deg at 70-79 % for no extra speed.
    1 kg in the hoppers lifts the nose 6 deg at rest.
    - MOT_THR_MAX 50 (was 90), MOT_SLEWRATE 200 (was 0); 45 vs 50 compared
    - Left pull is physical: outputs identical with the stick centred
    - Charts with nose angle, power and speed; recorder flushes every 10 rows
    - docs/03 SERVO1/3 MIN/MAX corrected to 1100/1900
    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
2026-10-20 Nose-down work: 10 deg trim tab tested and fitted, 8 deg tilt carriers, param backup
    - designs/trim: centre V trim tab on the bases' existing post screws
    (fit-gauge tuned: 99.5 mm apart, 12 mm forward; bases 4 mm below the
    V edges); 0/5/10 deg + gauge. 10 deg at 50 %: loaded nose 15.2 -> 13.4,
    empty 6.4 -> 3.9, empty speed 1.06 -> 1.18 m/s at the same current.
    - 55 % with the tab tested and rejected; MOT_THR_MAX back to 50
    - thruster_tilt_carrier.scad: 3/6/8 deg carriers (8 chosen, printed, to
    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
2026-10-20 8 deg tilt carriers fitted, MOT_THR_MAX 60, speed charts, plain M3 nut
    - Tilt + 10 deg tab at 50 %: loaded nose 9.2 deg, empty 0.7 deg; then
    60 % kept: loaded 12.3 deg / 1.10 m/s, empty 5.0 deg / 1.29 m/s
    (~11 drops at 100 m); 65 % tested and rejected
    - Charts: every pool setup (nose, speed, current, energy per metre) and
    speed progress from stock (0.8 m/s) to the kept setup
    - params/2026-10-20.param re-taken at end of day (only MOT_THR_MAX 50 -> 60)
    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
2026-10-22 GPS antenna cover (base + cap) STLs with README and fit check
    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
